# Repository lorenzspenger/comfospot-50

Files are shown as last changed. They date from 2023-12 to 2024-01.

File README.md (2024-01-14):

# Comfospot 50

Findings from reverse engineering the Zehnder Comfospot 50 to get it into Home Assistant.

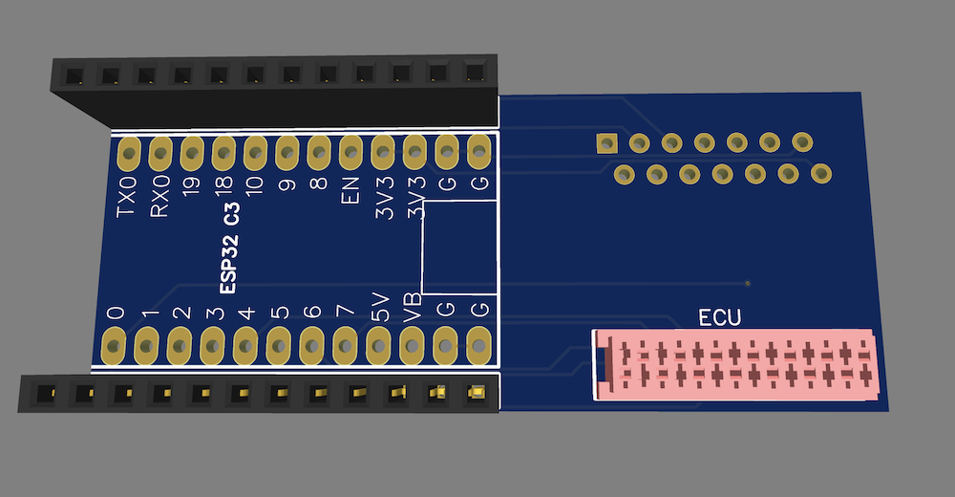
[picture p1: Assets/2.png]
Picture of the resulting PCB.


## Idea
While some efforts where made to analyze the [serial connection on the main board](https://kaspars.net/blog/zehnder-comfospot-protocol) of the ventilation system, I tried a more 'analog', less invasive route.
The idea was to put a microcontroller behind the button controls on the front of the device and intercept and manipulate the signals coming from, and going to the control panel.
To do this I had to find the correct connector. The [Würth Electronics WR-MM IDC Connector System](https://www.we-online.com/en/components/products/em/connectors/wire-to-board/wr-mm_mini_module) is used, with 14 Pins.

## Pin Definitions
### TO DO: Insert Pin definition picture
First I analyzed which pin was responsible for which button press and LED on the control panel. And the most important question was if there is a supply voltage to drive a microcontroller, preferably 3.3V.

## PCB
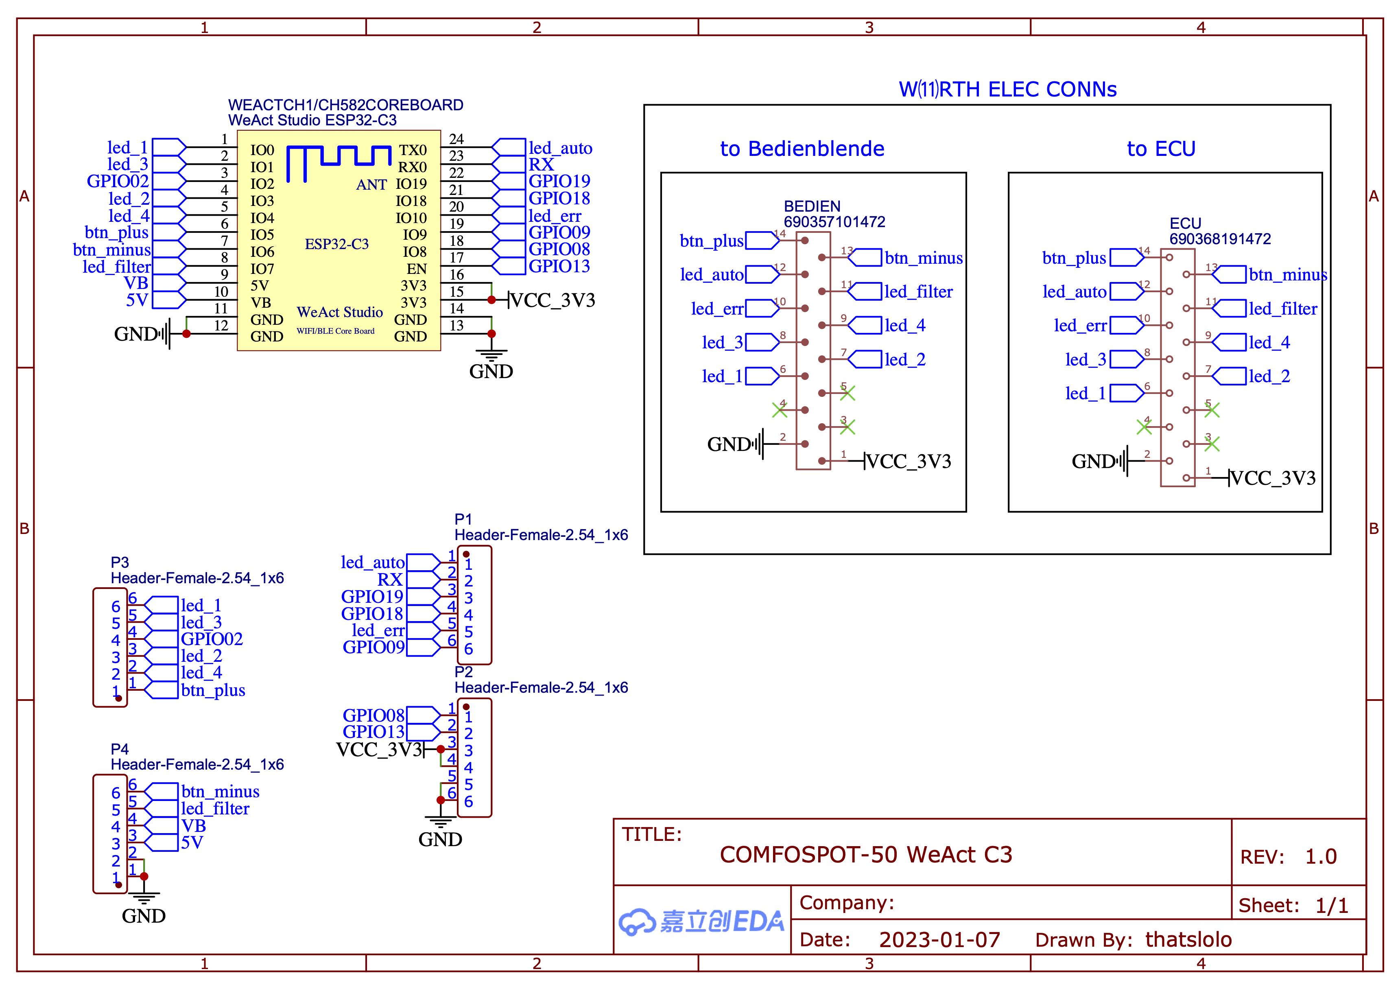
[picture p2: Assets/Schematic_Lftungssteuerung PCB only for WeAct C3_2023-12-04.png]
Schematics of project


I built a PCB which can be clipped directly onto the control panel and sit between it and the ecu of the system.
On the PCB we need an [__WeAct ESP32 C3__](https://github.com/WeActStudio/WeActStudio.ESP32C3CoreBoard), a __female__ and a __male WR-MM connector__.

## Home Assistant Integration

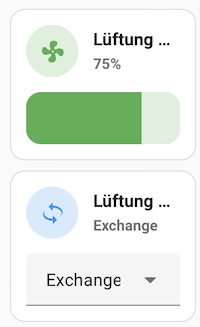
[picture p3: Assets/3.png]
image of integration of fan entity and direction select in Home Assistant dashboard


For the programming of the microcontroller I settled on ESPHome, since I'm quite familiar with the system and I can integrate it without any additional work into Home Assistant.

All functions which can be controlled from the control panel can be controlled from within HA.
* fan speed (readout and control)
* fan direction / exchange
* change filter and error LED
* reset filter

While all of these functions can be controlled from within HA, the control panel remains fully functional, and every state change triggered on the device itself will be reflected in HA.

## Limitations: 
### Comfospot can not be turned on remotely
Unfortunately the standby mode also cuts the power to the microcontroller and reenabling the fans remotely would not be possible anymore. A physical button press is required.
To prevent this from happening accidentally a 'Turn Off locked' switch is active by default.

### TO DO:
* ~~Add Gerber files~~
* Add BOM
* ~~Add YAML~~

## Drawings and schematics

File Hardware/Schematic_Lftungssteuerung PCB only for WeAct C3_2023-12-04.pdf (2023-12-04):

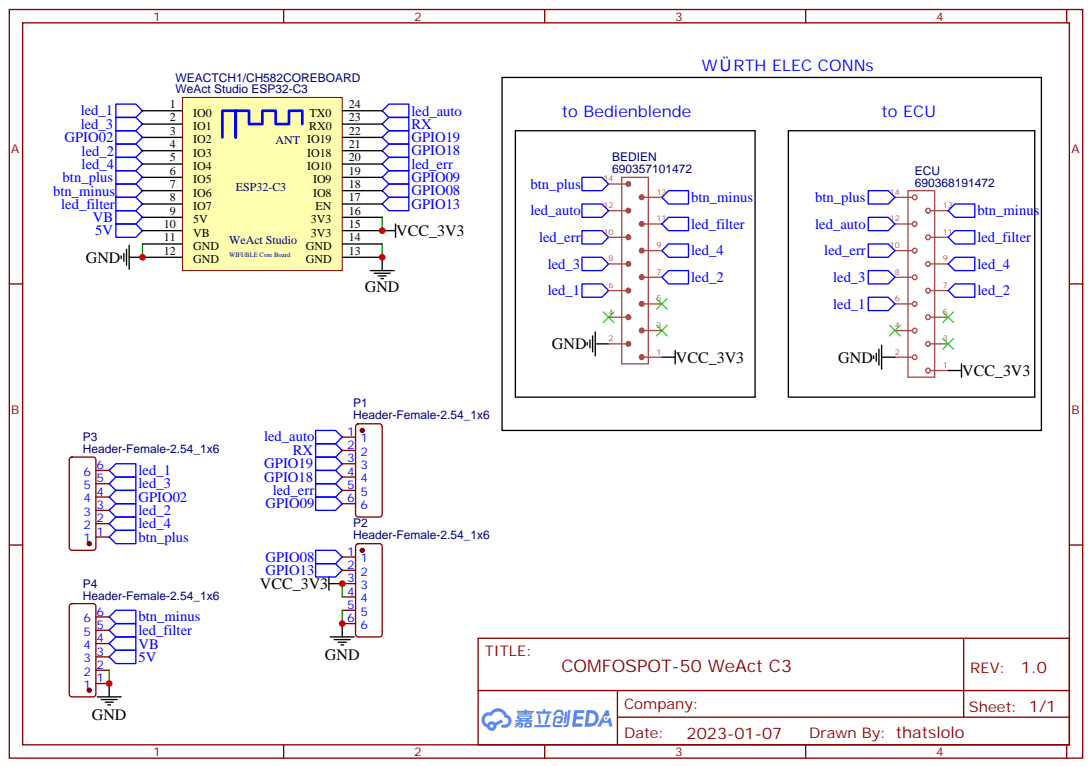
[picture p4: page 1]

WIFI/BLE Core Board

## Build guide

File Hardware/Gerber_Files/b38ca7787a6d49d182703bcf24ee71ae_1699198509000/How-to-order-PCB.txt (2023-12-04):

How to Order PCB

Please refer to:
https://docs.easyeda.com/en/PCB/Order-PCB

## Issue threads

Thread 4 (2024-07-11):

possible to add humidity and temperature sensor?

harryberlin, 2024-07-11:
Hello

very cool project.
Do you think it's easy to add an humidity and temperture sensor to get an automatic regulation implemented?
I never did program yaml, only python and C.
Is it possible to port to C?

would be nice to get an answer.

thatslolo, 2024-07-12:
Hi,

the esp has at least three unused GPIO. So it shouldn't be an issue to add an i2c T/H sensor such as AHT20 or SHT3 to the board. Even as a prototype since every port is broken out.
Software wise it would be easy to add in ESPHome, but I'm not sure which kind of automation you would suggest.

Concerning the port to C/(Micro-)Python:
ESPHome is used for easy integratio in Home Assistant. Most of the logic interacting with the Comfospot is implemented in lambda calls (inline C-like functions).

I do think I have some more docu of the reverse engineering I could provide if interested.

harryberlin, 2024-07-13:
Thanks for reply.

I did order the PCBs few days ago.
next order is about AHT20, ESP32-C3 and the connectors.

if you like you can send to avr-ibus@gmx.net

harryberlin, 2024-07-26:
So, i have received the pcbs and ESP32C3 WeAct Studio devices.
I don't know how the get upload your program.
Did setup home assitant on virtual box for the moment.
Could you guide me, how to get it working?

thatslolo, 2024-07-29:
basically you add the esphome addon and add the config via a package to a new device. https://esphome.io/guides/getting_started_hassio

[Software/lftung_xxx.yaml](https://github.com/thatslolo/comfospot-50/blob/592dd7704b8d5a9dc0bce380b7015109c28eae16/Software/lftung_xxx.yaml) is a working example.

harryberlin, 2024-08-17:
so, took a while to solder the pcb and upload firmware.
needed to compile at separted system, the raspberry 2 freezed after some time during compiling.
the connector on top is an other one, but it's working.
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

finally, i don't have the functions on dash.
do i need some further steps?
the overview in esphome is this
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

lorenzspenger, 2024-08-23:
Basically Home Assistant should discover the device on the network and you can add it to your dashboard from there. Seems like you didn't create your own config for the device which I would recommend. Also you can simply flash it from [here](https://lorenzspenger.github.io/Comfospot-50-installer/) and adopt it afterwards into your own ESPHome Dashbaord

harryberlin, 2024-08-29:
Got it working, after swap to raspberry 4 with official homeassistant image.
Thank you for your help.

in my case: yaml is such an annoying scripting language. i don't know, if i will understand this, to add some other features.

Closed 2024-09-11.

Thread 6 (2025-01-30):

Feature: AUTO Mode

indikat0r, 2025-01-30:
Hi,

in the Bathrooms i have that Humidity sensor integrated and they running in "auto" mode.
But that is not recognized, cause thats an extra LED.
How can i help to get that feature?
is it even possible?
im not very good in programming...

German:
In den Badezimmern, habe ich den Zender Feuchte Sensor mit in den Comfospot.
Dort laufen die auf AUTO, und haben eine extra LED.

Wie kann ich helfen das ich das angezeigt bekomme?
Wird vermutlich eine neue Platine sein, um diese AUTO LED auszulesen?
Programmieren ist nicht meine Stärke.

Gruß
Martin

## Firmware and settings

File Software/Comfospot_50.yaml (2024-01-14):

######################################################
######################################################
####### following substitutions have to ##############
#######     be declared in main yaml:   ##############
######################################################
######################################################

# substitutions:
#   device_name: Lüftung Wohnbereich
#   friendly_name_fan
#   gpio_led1:                GPIO0
#   gpio_led2:                GPIO3
#   gpio_led3:                GPIO1
#   gpio_led4:                GPIO4
#   gpio_led_filter_change:   GPIO10
#   gpio_led_error:           GPIO7  
#   gpio_output_plus:         GPIO19
#   gpio_output_minus:        GPIO18


######################################################
######################################################


esphome:
  on_shutdown:
    # priority: 700
    then:
      - output.turn_off: ventilation_plus
      - output.turn_off: ventilation_minus
  on_boot:
    then:
      - script.execute: init

# initialize filter runtime
      - if:
          condition:
            - lambda: 'return id(timestamp_last_filter_change) == 0;'
          then:
            - lambda: id(timestamp_last_filter_change) = id(my_time).timestamp_now();


time:
  - platform: homeassistant
    id: my_time
    timezone: Europe/Berlin


globals:
  - id: current_fan_speed
    type: int
    # restore_value: true
    initial_value: '-1'
  - id: current_set_speed
    type: int
    restore_value: true
  - id: speed_diff
    type: int
    restore_value: false
    initial_value: '0'
  - id: exhaust_active
    type: bool
    restore_value: false
    initial_value: 'false'
  - id: intake_active
    type: bool
    restore_value: false
    initial_value: 'false'

  - id: timestamp_last_filter_change
    type: float
    restore_value: true
    initial_value: '1699133782'

    # 0 = exchange, 1 = intake, 2 = exhaust
  - id: direction
    type: int
    restore_value: false
    initial_value: '0'

  - id: button_manipulation
    type: bool
    restore_value: false
    initial_value: 'false'





script:
  - id: retrieve_fan_speed
    mode: parallel
    then:
      - logger.log: "Checking fan speed..."
      - wait_until:
          condition:
            for: 
              time: 1250ms
              condition:
                binary_sensor.is_off: led_error
          timeout: 6500ms
      - wait_until:
          condition:
            for: 
              time: 1250ms
              condition:
                binary_sensor.is_on: led_1
          timeout: 6500ms
      - logger.log: "Fan speed retrieval started. Reading speed now."
      - lambda: |-
          id(current_fan_speed) = 0;
          if (id(led_1).state) id(current_fan_speed)++;
          if (id(led_2).state) id(current_fan_speed)++;
          if (id(led_3).state) id(current_fan_speed)++;
          if (id(led_4).state) id(current_fan_speed)++;
      - sensor.template.publish:
          id: sensor_current_fan_speed
          state: !lambda 'return id(current_fan_speed);'
      # - lambda: |-
      #     auto call = id(_fan).turn_on();
      #     call.set_speed(id(current_fan_speed));
      #     call.perform(); 
      - delay: 10ms
      - logger.log: 
          format: "Retrieved speed: %d"
          args: [ 'id(current_fan_speed)' ]
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

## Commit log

2023-12-04 added HW files
    [Drill_PTH_Through.DRL, Drill_PTH_Through_Via.DRL, Gerber_BoardOutlineLayer.GKO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]
2023-12-15 corrected error and filter LED GPIOs
    [Comfospot_50.yaml]
2024-01-13 Suppress compilation warning: Pin used in multiple places
    This change suppresses the following compilation warnings:
    Pin 5 is used in multiple places.
    Pin 6 is used in multiple places.
2024-01-13 Suppress compilation warning: Pin is a strapping pin
    This commit suppresses the following compilation warning:
    WARNING GPIO8 is a strapping PIN and should only be used for I/O with
    care. Attaching external pullup/down resistors to strapping pins can
    cause unexpected failures. See
    https://esphome.io/guides/faq.html#why-am-i-getting-a-warning-about-strapping-pins
2024-01-13 Add yamllint configuration and fix all warnings and errors
    [Comfospot_50.yaml]
2024-01-14 Revert "Add yamllint configuration and fix all warnings and errors"
    Accidentally pushed without a PR.
    This reverts commit 5c28cee254be1305cf8610aed75e20458a560907.
    [Comfospot_50.yaml]
2024-01-14 added logic to handle the case that Intake mode is impossible to set
2024-08-23 added ota provider to sample configs cleaned up yaml
2026-11-06 Store filter change timestamp as uint32_t
    A float rounds current unix timestamps to 128 s steps. The new
    filter_changed_at global (uint32_t, same 4 bytes, exact to the second)
    gets its own preference slot and is filled once at boot from the old
    float global timestamp_last_filter_change, which can be removed once
    every device has booted this firmware.
2026-11-06 Filter reset: time out after 15 s and report a failed reset
    The wait for the filter LED to go off had no timeout, so a reset the unit
    did not accept left the script running forever with button_manipulation
    set, and presses on the unit were no longer reflected in HA until reboot.
    Now it gives up after 15 s, logs a warning and notifies HA.
